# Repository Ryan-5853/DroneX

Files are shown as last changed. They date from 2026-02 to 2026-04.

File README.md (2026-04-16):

# DroneX(推进中)

推力矢量可回收火箭式无人机 —— 重心高于推力点，通过共轴反桨与二轴云台实现姿态控制，动力学特性类似 SpaceX Falcon 9 垂直着陆。

## 项目概述

DroneX 采用**单一推力源 + 推力矢量偏转**的设计：

| 特性 | 描述 |
| --- | --- |
| 推进方式 | 共轴反桨，向下产生推力，自然抵消反扭矩 |
| 重心位置 | 高于推力作用点（倒立摆模型） |
| 控制机构 | 二轴云台（俯仰+滚转），高端无刷舵机驱动 |
| 飞行模式 | 悬停、平移、垂直降落（含自由落体段） |

与常规多旋翼不同，本机重心在推力之上，固有不稳定，需闭环控制保持姿态。

## 目录结构

```
DroneX/
├── docs/              # 项目文档
│   ├── PLAN.md        # 总体规划（动力学、架构、开发阶段）
│   ├── REFERENCES.md  # 参考文献索引
│   └── literature/    # 文献摘编
├── sim/               # 仿真（MATLAB/Simulink）
│   ├── matlab/        # 动力学模型、控制器、脚本、工具函数
│   ├── simulink/      # Simulink 模型
│   ├── data/          # 仿真输出
│   └── docs/          # 仿真计划、动力学模型、验证标准
├── mechanical/        # 机械设计
│   ├── docs/          # 设计计划、机架/推进/云台说明
│   ├── cad/           # CAD 源文件
│   ├── models/        # STL/STEP 导出
│   ├── drawings/      # 工程图
│   └── bom/           # 物料清单
└── firmware/          # 飞控固件（STM32H743 + HAL）
    ├── DroneX_STM32H743_Firmware/   # CubeMX + Keil 工程（主工程）
    ├── docs/          # 飞控设计文档
    └── hal_project/   # 空白 HAL 工程导入位置
```

## 快速入门

### 仿真

1. 安装 MATLAB R2021b+ 与 Simulink
2. 进入仿真目录并运行：
   ```matlab
   cd sim/matlab
   init_path
   run_basic_sim
   ```
   或直接运行：`cd sim/matlab/scripts; run_basic_sim`
3. 悬停验证：`run_verify_hover`（定点悬停 / 水平平移）
4. 详见 [sim/README.md](sim/README.md)

### 文档入口

- [总体规划](docs/PLAN.md) — 动力学模型、系统架构、子系统规划、开发阶段
- [参考文献](docs/REFERENCES.md) — TVC、倒立摆、共轴旋翼、飞行控制等文献
- [仿真计划](sim/docs/SIMULATION_PLAN.md) — 仿真目标、模块、验证标准
- [动力学模型](sim/docs/dynamics_model.md) — 坐标系、方程、参数（与 params.m 对齐）
- [机械设计计划](mechanical/docs/DESIGN_PLAN.md) — 管架、共轴产品、高端无刷舵机、材料与尺寸
- [飞控设计](firmware/docs/FLIGHT_CONTROL_DESIGN.md) — 软件架构、控制流程、驱动规划

## 技术栈

| 模块 | 工具 / 平台 |
| --- | --- |
| 仿真 | MATLAB、Simulink |
| 飞控 | STM32H743、CubeMX/HAL、Keil MDK-ARM |
| 机械 | 管架为主、3D 打印、现成共轴产品、高端无刷舵机 |
| 文档 | Markdown |

## 开发阶段

| 阶段 | 内容 |
| ---- | --- |
| P0 | 建模与仿真 |
| P1 | 机械初版 |
| P2 | 下位机基础 |
| P3 | 控制闭环、悬停 |
| P4 | 降落逻辑、鲁棒性优化 |

详见 [docs/PLAN.md](docs/PLAN.md)。

## 许可证

（待定）

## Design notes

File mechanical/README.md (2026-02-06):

# DroneX 机械设计子系统

## 概述

本目录包含 DroneX 可回收火箭式无人机的机械设计内容，包括机架、共轴推进单元、二轴云台等结构与装配设计。加工方式以 **3D 打印** 为主，必要时采用 CNC 加工。

## 设计目标

- **机架**：管架为主，火箭式细长外形，底部起落架，兼顾重心/推力点位置
- **共轴反桨单元**：现成共轴产品，到货后补充规格与安装接口
- **二轴云台**：俯仰轴 + 滚转轴，高端无刷舵机驱动
- **电池/载荷布局**：保证重心在推力点之上，满足倒立摆动力学要求（整机 ≤ 1 kg）

## 目录结构

```
mechanical/
├── docs/              # 机械设计文档
│   ├── DESIGN_PLAN.md # 设计计划与关键参数
│   ├── frame/         # 机架相关文档
│   ├── coax_unit/     # 共轴推进单元文档
│   └── gimbal/        # 二轴云台文档
├── cad/               # CAD 源文件（Fusion 360 / FreeCAD / STEP）
├── models/            # 导出模型（STL、STEP，用于 3D 打印与仿真）
├── drawings/          # 工程图（装配图、零件图）
└── bom/               # 物料清单（BOM）
```

## 输出物

| 类型 | 说明 |
| --- | --- |
| CAD 模型 | 零件与装配体源文件 |
| 工程图 | 装配说明、零件标注、加工图 |
| BOM | 物料清单，含规格与数量 |
| STL/STEP | 3D 打印用模型、仿真/外协用 |

## 相关文档

- [项目总览](../../docs/PLAN.md) - DroneX 项目总体规划
- [机械设计计划](./docs/DESIGN_PLAN.md) - 材料选型、关键尺寸约束、设计流程

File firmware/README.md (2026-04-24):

# DroneX 飞控固件子系统

基于 HAL 库的飞控固件与外围驱动，面向 DroneX 推力矢量可回收火箭式无人机。

## 简介

本子系统基于 **STM32H743** 与 **STM32CubeMX/HAL**，从零编写飞控固件，实现：

- 实时控制循环（200–500 Hz）
- IMU 姿态估计（互补滤波或 EKF）
- 电调与云台电机驱动
- 遥控接收与串口遥测
- 安全逻辑（低电压、失控、急停）

## 目录结构

```
firmware/
├── docs/                              # 飞控设计文档
│   └── FLIGHT_CONTROL_DESIGN.md       # 飞控设计主文档
├── DroneX_STM32H743_Firmware/         # CubeMX + Keil 工程（主工程）
│   ├── Core/                          # 主控逻辑、HAL 配置
│   ├── Drivers/                       # HAL、CMSIS
│   ├── MDK-ARM/                       # Keil 工程文件
│   └── *.ioc                           # CubeMX 配置
├── hal_project/                       # 空白 HAL 工程导入位置（可选）
└── README.md                          # 本文件
```

- **DroneX_STM32H743_Firmware/**：STM32CubeMX 生成的 HAL 工程，含 Keil MDK-ARM 项目文件
- **docs/**：飞控设计、驱动规划、控制流程等文档

## 硬件平台

| 组件 | 选型 |
| --- | --- |
| 主控 | STM32H743 |
| IMU | MPU6050 或 BMI088 |
| 电调 | BLHeli 或 ESC32 |
| 云台舵机 | 高端无刷舵机，PWM / SBUS 等舵机协议 |

## 参考系与物理量单位规定

    世界参考系：在初始化时与机体参考系对齐，随后保持与地面相对位姿不变
    机体参考系：俯视飞控板正面，向上为y轴正方向，向右为x轴正方向，垂直飞控板正面向上为z轴正方向，原点在机体质心
    传感器参考系：近似认为与飞控板姿态相同，但是原点在飞控板中心
    矢量单元参考系：俯视矢量舵盘，使两突出舵臂分别指向平面直角坐标系的x、y正方向，称为x臂和y臂，垂直矢量舵盘朝上为z正方向
                    两舵机分别称为x舵机、y舵机，当舵机臂水平于地面时，认为舵机打角为0，向上为正，向下为负，按照对称限幅归一化到-1~1
                    矢量单元朝向以roll/pitch表示，其中roll为绕y轴的转角，pitch为绕x轴的转角，遵循右手螺旋定则。即x舵机正向打角时，x臂上抬，矢量单元绕y轴逆向旋转；y舵机正向打角时，y臂上抬，矢量单元绕x轴正向旋转；

    长度、位移均以m为单位；质量以kg为单位；力以N为单位；角度以360分度为单位；时间以s为单位

## 开发阶段

对应项目主计划 [PLAN.md](../docs/PLAN.md) 中：

- **P2：下位机基础** — 飞控框架、IMU、电调、云台驱动，可手动操控的固件
- **P3：控制闭环** — 姿态闭环、悬停、简单轨迹

## 相关文档

- [飞控设计文档](docs/FLIGHT_CONTROL_DESIGN.md) — 软件架构、控制流程、驱动规划、安全逻辑
- [项目主计划](../docs/PLAN.md) — DroneX 总体规划、系统架构
- [动力学模型](../sim/docs/dynamics_model.md) — 坐标系、运动方程
- [飞行控制文献](../docs/literature/04-flight-control-and-estimation.md) — 姿态控制、状态估计
- [机械设计计划](../mechanical/docs/DESIGN_PLAN.md) — 云台舵机选型、限位

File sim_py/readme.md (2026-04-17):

# DroneX控制器仿真工程

## 仿真系统结构

### 接口数据结构定义
    按照信号类型分为位姿信号、控制信号、执行信号、力矩信号
    按照逻辑类型分为真值(物理世界理想信号)、采样值(考虑传感器噪声)、估计值(考虑建模误差与随机行为)

    一共有以下几种数据结构：
    POS_truth{//位姿真实值
        disp_xyz:三轴质心位移(世界参考系)
        att_quat:姿态四元数(世界参考系->机体参考系)
        vel_xyz:三轴质心线速度(世界参考系)
        acc_xyz:三轴质心加速度(世界参考系)
        angv_xyz:三轴角速度(机体参考系)
        anga_xyz:三轴角加速度(机体参考系)
    }

    Sensor_truth{//传感器系位姿真实值
        angv_xyz:三轴角速度(传感器参考系)
        acc_xyz:三轴加速度(传感器参考系)
    }
    //以上是Dynamics模块

    Sensor_obs{//传感器观测到的值，Sensor_truth带噪声
        angv_xyz:三轴角速度(传感器参考系)
        acc_xyz:三轴加速度(传感器参考系)
    }

    //以上是Sensor模块

    POS_est{//预测的机体位姿
        disp_xyz:三轴质心位移(世界参考系)
        att_quat:姿态四元数(世界参考系->机体参考系)
        vel_xyz:三轴质心线速度(世界参考系)
        acc_xyz:三轴质心加速度(世界参考系)
        angv_xyz:三轴角速度(机体参考系)
        anga_xyz:三轴角加速度(机体参考系)
    }

    //待定：预测算法的建模误差

    //以上是Estimator模块

    Ctrl_output{//控制器的输出
        thrust_xyz:目标推力矢量(机体系)
        torque_xyz:目标旋转扭矩(机体系)
    }

    //以上是Controller模块

    Ctrl_cmd{直接输出给执行器的控制信号
        Servo_x:使矢量单元沿x轴旋转的舵机占空比(在限幅内归一化)
        Servo_y:使矢量单元沿y轴旋转的舵机占空比(在限幅内归一化)
        Motor_P:正桨电机占空比
        Motor_N:反桨电机占空比
    }

    //以上是Allocator模块

    Actor_output{执行器输出的真实力矩
        Force_xyz:执行器作用在机体质心上的三轴力
        Torque_xyz:执行器作用在机体上、绕机体系三轴旋转的力矩
    }

    //以上是Actuator模块

    送入Dynamics积分

### Sensor(传感器模块)

模拟实机传感器模块的工作

读入真实位姿数据POS_truth,
    Sensor_err{//传感器安装误差
        disp_xyz:传感器参考系原点与机体参考系原点(质心)的位移误差
        disp_err:建模误差比例
        att_quat:机体参考系到传感器参考系的旋转姿态差
        att_err:建模误差比例
    }
以此为依据计算传感器系的真实位姿
为以上位姿添加噪声，模拟传感器噪声，传出Sensor_obs

### Estimator(位姿估计模块)

从传感器数据估计机体位姿

读入传感器系带噪声读数Sensor_obs
矫正、逆变换得到机体系位姿
位姿估计算法得到POS_est,传出

### Controller(控制器)

将位姿与目标位姿比较，输出控制矢量

读入估计位姿POS_est,更新控制器,输出Ctrl_output

### Allocator(执行器映射层)

根据目标控制矢量调整各执行器控制信号

读入Ctrl_output，通过执行器建模，计算执行器控制信号Ctrl_cmd

### Actuator(执行器模块)

根据控制信号，模拟执行器行为

读入Ctrl_cmd，根据执行器建模，加入噪声、随机行为、滞后、限幅等，输出模拟的实际输出物理量Actor_output

### Dynamics(物理仿真模块)

根据真实位姿和执行器实际输出更新真实位姿

读入Actor_output，按照运动学模型更新真实位姿，输出POS_truth

## 参考系与物理量单位规定

    世界参考系：在初始化时与机体参考系对齐，随后保持与地面相对位姿不变
    机体参考系：俯视飞控板正面，向上为y轴正方向，向右为x轴正方向，垂直飞控板正面向上为z轴正方向，原点在机体质心
    传感器参考系：近似认为与飞控板姿态相同，但是原点在飞控板中心
    矢量单元参考系：俯视矢量舵盘，使两突出舵臂分别指向平面直角坐标系的x、y正方向，称为x臂和y臂，垂直矢量舵盘朝上为z正方向
                    两舵机分别称为x舵机、y舵机，当舵机臂水平于地面时，认为舵机打角为0，向上为正，向下为负，按照对称限幅归一化到-1~1
                    矢量单元朝向以roll/pitch表示，其中roll为绕y轴的转角，pitch为绕x轴的转角，遵循右手螺旋定则。即x舵机正向打角时，x臂上抬，矢量单元绕y轴逆向旋转；y舵机正向打角时，y臂上抬，矢量单元绕x轴正向旋转；

    长度、位移均以m为单位；质量以kg为单位；力以N为单位；角度以360分度为单位；时间以s为单位

## 交互式可视化模块

可以使用交互式可视化模块实时观察仿真状态，支持输入期望姿态、期望速度、风力风向和扰动力，并以动画形式显示：

- 三维飞行器几何体（筒状机体 + 下方矢量单元）
- 飞行轨迹、推力方向
- 传感器读数、控制器输出、执行器输出

运行方式：

```bash
python -m sim_py.visualization
```

默认是紧凑UI（更流畅，组件更少）。如果需要完整调参滑块，可使用：

```bash
python -m sim_py.visualization --full-ui
```

可视化模块默认会加载一组首轮标定参数（见 sim_py/calibration.py），用于快速进入闭环调参状态。

界面右侧提供在线调参滑块，可实时修改：

- 控制器位置/速度环增益（Kp/Kd/Ki）
- 控制器姿态/角速度环增益（Kp/Kd/Ki）
- 推力与扭矩限幅
- 分配器推力映射增益、执行器电机推力增益

如果只做快速自检（不弹出GUI）：

```bash
python -m sim_py.visualization --headless-steps 200
```

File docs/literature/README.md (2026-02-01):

# 文献摘编目录

本目录按技术主题对 [REFERENCES.md](../REFERENCES.md) 中的文献做要点摘编，并与 [PLAN.md](../PLAN.md) 的工程描述对应，便于建模、控制与仿真时查阅。

| 文档 | 主题 | 与 DroneX 的关联 |
|---|---|---|
| [01-TVC-and-rocket-landing.md](01-TVC-and-rocket-landing.md) | 推力矢量控制与火箭垂直着陆 | 二轴云台 TVC、推力线不通过重心、力矩与力分配 |
| [02-inverted-pendulum-and-underactuated.md](02-inverted-pendulum-and-underactuated.md) | 倒立摆与欠驱动系统 | 重心高于推力点、开环不稳定、串级控制与 LQR |
| [03-coaxial-rotor-and-propulsion.md](03-coaxial-rotor-and-propulsion.md) | 共轴旋翼与推进器建模 | 共轴反桨、推力–转速关系、干扰系数 |
| [04-flight-control-and-estimation.md](04-flight-control-and-estimation.md) | 飞行控制与状态估计 | 姿态/位置 PID 或 LQR、控制分配、IMU 互补滤波或 EKF |
| [05-simulation-and-dynamics.md](05-simulation-and-dynamics.md) | 仿真与动力学建模 | 坐标系、平动/转动方程、Simulink/CIL、云台与推进器模型 |

**使用建议**：先阅 [REFERENCES.md](../REFERENCES.md) 获取完整书目与分类，再按需打开上表对应摘编文档查看公式与实现要点。

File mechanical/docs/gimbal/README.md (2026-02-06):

# 二轴云台

## 功能

俯仰轴 + 滚转轴，将推力矢量偏转，实现姿态控制与水平加速度。由两个**高端无刷舵机**驱动。

## 已确认

- **驱动方式**：高端无刷舵机（替代无刷直驱，降低驱动、通信、校准难度，性能相近）
- **选型**：待定

## 设计要点

- 轴系正交布置，俯仰 + 滚转
- 舵机协议：PWM / SBUS 等，便于飞控输出
- 机械限位与软件限位
- 线缆走线不干扰转动

## 选型后待补充

- 舵机型号、额定电压/电流
- 扭矩、角度范围、死区
- 安装孔位、尺寸、重量
- 通信协议与接线方式

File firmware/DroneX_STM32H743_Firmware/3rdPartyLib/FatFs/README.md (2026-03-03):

# FatFs - Generic FAT Filesystem Module

FatFs R0.15 (ChaN) - 嵌入式 FAT 文件系统库。

本目录包含 FatFs 核心源码，由 SD 卡驱动层引用。磁盘 I/O 接口（diskio）在 `User/Driver/SD/diskio_sd.c` 中实现。

## 文件说明

- `ff.c`, `ff.h` - FatFs 核心
- `ffconf.h` - 项目配置（无 RTOS、无 LFN、支持 f_printf）
- `diskio.h` - 磁盘 I/O 接口声明

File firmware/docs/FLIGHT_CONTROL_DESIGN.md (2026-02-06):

# DroneX 飞控设计文档

> 依据 [PLAN.md](../../docs/PLAN.md) 第 5.2 节及第 7 节「下位机计划」编写。

---

## 〇、已确认技术选型

| 项目 | 选择 |
| --- | --- |
| **主控** | STM32H743 |
| **HAL 库** | STM32CubeMX 生成 |
| **控制周期** | 200–500 Hz（内环 500 Hz，外环 100–200 Hz） |
| **IMU** | MPU6050 或 BMI088 |
| **电调** | BLHeli 或 ESC32 |
| **云台舵机** | 高端无刷舵机，PWM / SBUS 等舵机协议 |
| **姿态估计** | 互补滤波（首版）或 EKF（后续） |

---

## 一、目标与范围

### 1.1 目标

- 基于 HAL 库从零编写飞控固件与外围驱动
- 实现 P2 阶段「下位机基础」：飞控框架、IMU、电调、云台驱动
- 为 P3 控制闭环提供可烧录固件与驱动库

### 1.2 范围

- 飞控主控：STM32H743 + CubeMX/HAL，实时控制循环
- IMU：姿态估计（互补滤波或 EKF）
- 电调：主推进电机转速控制
- 云台舵机：高端无刷舵机（PWM/SBUS 等，驱动与校准简单）
- 通信：遥控接收、串口/无线遥测
- 安全逻辑：低电压保护、失控保护、急停

### 1.3 对应交付物（P2）

| 交付物 | 说明 |
| --- | --- |
| 可烧录固件 | 可手动操控的固件（油门、云台） |
| 驱动库 | IMU、ESC、云台舵机等驱动模块 |
| 参数配置工具 | 串口/地面站调参（可选） |

---

## 二、硬件平台

### 2.1 系统架构（引自 PLAN.md）

```mermaid
flowchart LR
    subgraph hw [硬件/下位机]
        FC[飞控主控]
        IMU[IMU]
        ESC[电调]
        GimbalMotor[云台舵机驱动]
    end
    
    subgraph sw [软件/控制]
        Est[状态估计]
        Ctrl[控制器]
        Alloc[控制分配]
    end
    
    FC --> IMU
    FC --> ESC
    FC --> GimbalMotor
    Est --> Ctrl
    Ctrl --> Alloc
    Alloc --> ESC
    Alloc --> GimbalMotor
```

### 2.2 主控

| 参数 | 规格 |
| --- | --- |
| 型号 | STM32H743 |
| 主频 | 480 MHz |
| 外设需求 | I2C（IMU）、PWM（电调、云台）、UART、ADC（电池电压） |

### 2.3 IMU

| 型号 | 接口 | 备注 |
| --- | --- | --- |
| MPU6050  | I2C | 六轴，成本低，易上手 |
| BMI088 | SPI/I2C| 精度更高，适合正式飞行 |

### 2.4 电调

| 类型 | 协议 | 备注 |
| --- | --- | --- |
| BLHeli | PWM / OneShot  | 通用，易采购 |
| ESC32 | UART/串口协议  | 闭环转速，可扩展 |

### 2.5 云台舵机

- 高端无刷舵机（参见 [mechanical/docs/DESIGN_PLAN.md](../../mechanical/docs/DESIGN_PLAN.md) 选型）
- 驱动方式：PWM / SBUS 等舵机协议，飞控输出脉宽或总线指令即可，无需 FOC、编码器、校准

### 2.6 通信接口

| 用途 | 接口 | 说明 |
| --- | --- | --- |
| 遥控接收 | SBUS/PPM | 油门、姿态指令、模式切换 |
| 遥测 | UART | 串口参数、状态上传 |
| 无线遥测 | 可选扩展 | WiFi/数传模块 |

---

## 三、软件架构

### 3.1 模块划分

| 层级 | 模块 | 职责 |
| --- | --- | --- |
| 应用层 | 状态估计 | IMU → 姿态、角速度 |
| 应用层 | 控制器 | 姿态/位置 PID 或 LQR |
| 应用层 | 控制分配 | 期望力/力矩 → T + (α, β) |
| 驱动层 | IMU 驱动 | I2C/SPI 读写、数据解析 |
| 驱动层 | ESC 驱动 | PWM/OneShot 输出 |
| 驱动层 | 云台驱动 | PWM/SBUS 舵机指令输出 |
| 驱动层 | 通信 | 遥控解析、串口遥测 |
| 系统层 | 任务调度 | 定时器、优先级、安全逻辑 |

### 3.2 任务调度

- **高优先级**：内环控制（角速度）500 Hz
- **中优先级**：外环控制（姿态、位置）100–200 Hz
- **低优先级**：遥测、参数更新、安全检测

实现方式：定时器中断 + 主循环，或 RTOS（FreeRTOS）按需引入。

---

## 四、控制流程

```mermaid
flowchart TB
    IMU[IMU 原始数据] --> Est[姿态估计]
    Est --> Att[姿态/角速度]
    RC[遥控指令] --> Pos[位置/姿态指令]
    Att --> Ctrl[姿态控制器]
    Pos --> Ctrl
    Ctrl --> Alloc[控制分配]
    Alloc --> ESC[ESC 推力 T]
    Alloc --> Gimbal[云台角 alpha beta]
    ESC --> Motor[主推进电机]
    Gimbal --> GimbalMotor[云台舵机]
```

数据流：IMU → 姿态估计 → 姿态/位置控制 → 控制分配 → ESC + 云台驱动。

坐标系与动力学约定参见 [sim/docs/dynamics_model.md](../../sim/docs/dynamics_model.md)。

---

## 五、驱动层规划

### 5.1 IMU 驱动

- 初始化：量程、采样率、滤波
- 数据读取：陀螺、加速度计原始值
- 单位转换：转为 rad/s、m/s²
- 对齐：机体系与 IMU 安装方向

### 5.2 电调协议

- PWM：1–2 ms 脉宽映射推力
- OneShot125/OneShot42：缩短最小脉宽，提高分辨率
- ESC32：若采用，需实现串口协议解析

### 5.3 云台舵机驱动

- **PWM 舵机**：脉宽映射期望角度（如 1–2 ms 对应角度范围）
- **SBUS 舵机**：若采用总线舵机，需解析 SBUS 协议或使用专用舵机库
- 限位：软件限位 + 机械限位（与 [mechanical/docs/gimbal/README.md](../../mechanical/docs/gimbal/README.md) 对齐）

### 5.4 遥控接收

- SBUS：串口协议，多通道
- PPM：单线多通道 PWM
- 解析：油门、俯仰/滚转/偏航指令、模式开关

### 5.5 串口遥测

- 输出：姿态、角速度、云台角、推力、电池电压
- 格式：自定义或 MAVLink 等标准协议（可选）

---

## 六、安全逻辑

| 项目 | 触发条件 | 动作 |
| --- | --- | --- |
| 低电压保护 | 电池电压 < 阈值 | 降推力、告警、逐步降落 |
| 失控保护 | 遥控信号丢失超时 | 悬停/降落/急停（可配置） |
| 急停 | 遥控急停开关 | 立即切断推力 |
| 上电自检 | 启动时 | IMU 校准、云台归中、电调初始化 |

---

## 七、与 HAL 工程的关系

### 7.1 hal_project 目录用途

- 本目录下 `hal_project/` 用于存放 STM32CubeMX 生成的 HAL 库空白工程
- 用户导入工程后，自研代码（状态估计、控制器、驱动）放在独立目录或 `hal_project/Core/` 下的自研模块中

### 7.2 CubeMX 配置建议

- 时钟：HSE + PLL，主频 480 MHz
- 定时器：用于控制周期（如 2 ms → 500 Hz）
- I2C：IMU（MPU6050/BMI088）
- PWM：电调通道、云台电机
- UART：遥控、遥测
- ADC：电池电压采样

### 7.3 自研代码与 HAL 的集成方式

- 在 `hal_project/Core/` 下创建 `dronex/` 或类似子目录，存放飞控应用与驱动
- 主循环或定时器中断中调用 `dronex_task_run()` 等入口
- 避免在 HAL 生成代码区域内手改，通过 `USER CODE` 块或外部调用集成

---

## 八、里程碑与依赖

| 子任务 | 依赖 | 产出 |
| --- | --- | --- |
| M0：框架搭建 | HAL 工程导入 | 空循环、定时器、串口打印 |
| M1：IMU 驱动 | 框架 | IMU 数据读取与单位转换 |
| M2：电调驱动 | 框架 | PWM 输出、推力可控 |
| M3：云台驱动 | 框架 | 云台角可控 |
| M4：姿态估计 | IMU 驱动 | 互补滤波姿态输出 |
| M5：开环操控 | M1–M4 | 可手动操控的固件 |
| M6：闭环控制 | M5 + sim 参数  | 姿态闭环、悬停（P3） |

与 [PLAN.md](../../docs/PLAN.md) P2/P3 阶段对应：M0–M5 对应 P2，M6 对应 P3。

---

## 九、参考与引用

- [PLAN.md](../../docs/PLAN.md) §5.2 下位机/驱动子系统
- [PLAN.md](../../docs/PLAN.md) §6 开发阶段 P2、P3
- [sim/docs/dynamics_model.md](../../sim/docs/dynamics_model.md) — 坐标系、运动方程
- [docs/literature/04-flight-control-and-estimation.md](../../docs/literature/04-flight-control-and-estimation.md) — 姿态控制、状态估计、控制分配
- [mechanical/docs/DESIGN_PLAN.md](../../mechanical/docs/DESIGN_PLAN.md) — 云台舵机选型、限位

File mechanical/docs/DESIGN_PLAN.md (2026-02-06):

# DroneX 机械设计计划

> 依据 [PLAN.md](../../../docs/PLAN.md) 第 5.3 节及第 7 节细化方向编写。

## 〇、已确认设计决策（2025-02 更新）

| 项目 | 决策 |
| --- | --- |
| **整机重量** | ≤ 1 kg |
| **飞行时间** | 调试阶段不限，可有线供电 |
| **机架形式** | **管架为主**，火箭外形、细长、底部起落架 |
| **推进单元** | 现成共轴产品 [淘宝 871597014800](https://item.taobao.com/item.htm?id=871597014800) |
| **云台驱动** | **高端无刷舵机**（驱动、通信、校准简单，性能接近无刷直驱） |
| **桨罩** | 暂不定，后续补充 |

---

## 一、设计约束与目标

### 1.1 力学约束

| 约束项 | 要求 |
| --- | --- |
| **重心位置** | 重心必须高于推力作用点（倒立摆稳定所需）  |
| **推力点** | 与共轴推进器中心、云台旋转中心一致 |
| **对称性** | 质量分布尽量对称，减小惯性积 |

### 1.2 加工约束

| 项目 | 选择 |
| --- | --- |
| **主加工方式** | 3D 打印（FDM / 光固化）  |
| **补充加工** | CNC（金属件、高精度件）  |
| **材料** | 待定，见 §2 材料选型 |

---

## 二、材料选型

### 2.1 3D 打印材料（初版建议）

| 用途 | 推荐材料 | 特性 |
| --- | --- | --- |
| 机架主体 | PLA / PETG | 易打印、成本低、强度够 |
| 云台结构件 | PETG / ABS | 韧性好、耐冲击 |
| 桨罩 / 护壳  | PLA / TPU | 轻量、可柔性（TPU） |
| 高负荷关节 | 尼龙 / 碳纤增强 | 强度高、耐磨（可选） |

### 2.2 金属件（如采用 CNC）

| 用途 | 推荐材料 |
| --- | --- |
| 云台转轴 | 铝合金 6061 |
| 电机安装板 | 铝合金 2mm+ |
| 关键紧固件 | 不锈钢 M2/M3 |

---

## 三、关键尺寸约束

### 3.1 重心与推力点

```
        ↑ Z (竖直向上)
        │
        │    ● 重心 (CG)
        │    │
        │    │  h_cg   （重心到推力点垂直距离，需 > 0）
        │    │
        │    ▼ 推力作用点 (CP) ← 云台旋转中心
        │
        └──────────────────→
```

- **h_cg**：重心到推力点垂直距离，建议初版 50–150 mm
- **横向偏心**：尽量控制在 5 mm 以内

### 3.2 共轴反桨单元

| 参数 | 初版建议 | 说明 |
| --- | --- | --- |
| 桨直径 | 5–7 inch | 视推力与效率需求 |
| 上下桨间距 | 待仿真/试验  | 过小易干扰，过大增高度 |
| 桨罩直径 | 略大于桨径 | 兼顾保护与气流 |

### 3.3 二轴云台

| 参数 | 初版建议 | 说明 |
| --- | --- | --- |
| 俯仰角范围 | ±15°–±25° | 满足姿态控制需求 |
| 滚转角范围 | ±15°–±25° | 同上 |
| 偏转速度 | 待电机选型 | 需满足控制带宽 |
| 减速比 | 待定 | 兼顾力矩与响应 |

---

## 四、子系统设计要点

### 4.1 机架

- **形式**：**管架为主**，火箭式细长外形，底部起落架支撑
- **安装点**：电池舱、飞控舱、云台基座、共轴单元
- **强度**：校核悬停 + 最大偏转力矩下的应力

### 4.2 共轴反桨单元

- **选型**：采用现成共轴产品（见上方链接），降低开发量
- **桨罩**：暂不定，待推进单元到货后视安装接口决定
- **散热**：按产品说明，必要时加通风开孔

### 4.3 二轴云台

- **轴系**：俯仰轴 + 滚转轴，正交布置
- **电机**：高端无刷舵机（PWM/SBUS 等舵机协议），待选型后补充规格表
- **限位**：机械限位 + 软件限位

### 4.4 电池与载荷布局

- **电池**：尽量上置，配合重心要求
- **飞控/IMU**：靠近重心，减少振动
- **线缆**：走线不干扰云台转动

---

## 五、设计流程与里程碑

| 阶段 | 工作内容 | 交付物 |
| --- | --- | --- |
| **M0：概念** | 草图、尺寸估算、材料初选 | 概念草图、参数表 |
| **M1：详细设计** | 机架、共轴单元、云台 CAD 建模 | 零件与装配模型 |
| **M2：工程图** | 出图、BOM、加工说明 | 图纸、BOM |
| **M3：样机** | 打印/加工、装配、重心测量 | 可装配样机 |

---

## 六、待定事项

1. **推进单元规格**：到货后补充桨径、推力、安装尺寸、重量
2. **云台舵机规格**：选型后补充扭矩、角度范围、安装尺寸、重量、协议
3. **管架尺寸**：直径、壁厚、接头形式（待推进单元/云台尺寸确定）
4. **起落架**：支腿形式、展开角度、触地面积
5. **标准件**：螺丝、轴承规格统一

---

## 七、参考与引用

- [PLAN.md](../../../docs/PLAN.md) §1.2 关键技术参数
- [PLAN.md](../../../docs/PLAN.md) §5.3 机械设计子系统
- [PLAN.md](../../../docs/PLAN.md) §6 开发阶段 P1：机械初版

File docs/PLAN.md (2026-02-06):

# DroneX 可回收火箭式无人机计划文档

## 一、项目概念概述

### 1.1 核心设计理念

本项目设计一款**重心高于推力作用点**的无人机，通过**推力矢量控制 (TVC)** 实现姿态稳定与运动控制，力学特性类似 SpaceX Falcon 9 垂直着陆阶段的倒立摆系统。

```mermaid
flowchart TB
    subgraph propulsion [推进系统]
        Coax[共轴反桨推进器]
        TVC[二轴云台推力矢量]
    end
    
    subgraph dynamics [动力学特性]
        CG[重心高于推力点]
        Unstable[固有不稳定]
        Pendulum[倒立摆模型]
    end
    
    subgraph control [控制方式]
        Gimbal[云台偏转]
        ThrustDir[推力方向控制]
    end
    
    Coax --> TVC
    TVC --> ThrustDir
    CG --> Unstable
    Unstable --> Pendulum
    ThrustDir --> Pendulum
```

### 1.2 关键技术参数

| 特性 | 描述 |
| --- | --- |
| **推进方式** | 共轴反桨，向下产生推力，自然抵消反扭矩 |
| **重心位置** | 高于推力作用点（类似火箭着陆姿态） |
| **控制机构** | 二轴云台（俯仰+滚转），由两个高端无刷舵机驱动 |
| **飞行模式** | 悬停、平移、垂直降落（含自由落体段） |

**云台轴系选型**：采用俯仰+滚转，直接映射姿态控制需求，响应快、耦合小。偏航控制可通过共轴双桨轻微转速差或后续扩展方案实现。

### 1.3 与常规多旋翼的差异

- **常规多旋翼**：多个电机分散布局，通过各电机转速差实现姿态控制，重心通常低于或接近推力平面
- **本设计**：单一推力源 + 推力矢量偏转，重心在推力之上，控制难度更高但机械结构更紧凑

---

## 二、动力学模型

### 2.1 坐标系定义

- **惯性系**：地面固定，Z 轴向上
- **机体系**：原点在重心，随机体旋转
- **推力系**：随云台偏转，描述推力方向

### 2.2 主要方程

**平动**（牛顿第二定律）：

```
m·a = F_thrust + m·g + F_disturbance
```

其中 `F_thrust` 由云台偏转角 (θ_pitch, θ_roll) 和推力幅值 T 决定。

**转动**（欧拉方程）：

```
I·ω̇ + ω × (I·ω) = τ_thrust + τ_disturbance
```

`τ_thrust` 由推力作用点相对重心的力臂产生。

**倒立摆特性**：重心在推力之上时，推力偏转产生的力矩可稳定姿态，但开环系统不稳定，需闭环控制。

### 2.3 推力矢量与云台关系

云台偏转 (α, β) 将推力从机体 Z 轴偏转至空间方向，产生：

- 姿态控制力矩（推力线不通过重心）
- 水平加速度（推力有水平分量）

---

## 三、系统架构

```mermaid
flowchart LR
    subgraph mech [机械设计]
        Frame[机架]
        CoaxUnit[共轴推进单元]
        Gimbal[二轴云台]
    end
    
    subgraph hw [硬件/下位机]
        FC[飞控主控]
        IMU[IMU]
        ESC[电调]
        GimbalMotor[云台电机驱动]
    end
    
    subgraph sw [软件/控制]
        Est[状态估计]
        Ctrl[控制器]
        Alloc[控制分配]
    end
    
    subgraph sim [仿真]
        Phys[物理仿真]
        Env[环境模型]
    end
    
    Frame --> CoaxUnit
    Frame --> Gimbal
    CoaxUnit --> Gimbal
    FC --> IMU
    FC --> ESC
    FC --> GimbalMotor
    Est --> Ctrl
    Ctrl --> Alloc
    Alloc --> ESC
    Alloc --> GimbalMotor
    Phys --> sw
```

---

## 四、已确认的技术选型

| 项目 | 选择 |
| --- | --- |
| 仿真工具 | MATLAB（含 Simulink） |
| 飞控平台 | STM32H743，从 HAL 库自研飞控 |
| 机械加工 | 3D 打印为主，必要时 CNC |
| 文档格式 | Markdown |
| 云台轴系 | 俯仰 + 滚转 |

---

## 五、子系统规划

### 5.1 仿真子系统 (`/sim`)

**目标**：在实机开发前验证动力学模型和控制算法。

**工具链**：MATLAB（含 Simulink）

**已实现**（MATLAB 脚本）：

- 刚体动力学（rigid_body_ode）、推力模型（thrust_model）
- 姿态控制器、位置控制器（attitude_controller、position_controller）
- 工具函数：四元数/欧拉角、thrust_dir_to_att、animate_drone
- 运行脚本：run_basic_sim、run_verify_hover（定点悬停、水平平移验证）
- 参数配置：params.m

**内容**：

- 刚体动力学仿真（MATLAB/Simulink）
- 推进器模型：推力-转速关系、共轴干扰系数
- 云台动力学：俯仰+滚转二轴、电机响应、机械限位
- 控制器在环仿真 (CIL)
- 可选：Simscape Multibody 用于机械/接触仿真

**输出**：验证过的控制参数、轨迹规划结果。

### 5.2 下位机/驱动子系统 (`/firmware`)

**目标**：基于 HAL 库从零编写飞控固件与外围驱动。

**硬件平台**：STM32H743，工程位于 `firmware/DroneX_STM32H743_Firmware/`（CubeMX + Keil MDK-ARM）

**内容**：

- **飞控主控**：STM32H743 + CubeMX/HAL，实时控制循环 (200–500 Hz)
- **IMU**：MPU6050 / BMI088，姿态估计（互补滤波或 EKF）
- **电调**：BLHeli/ESC32，主推进电机转速控制
- **云台电机**：高端无刷舵机（PWM/SBUS 等舵机协议，驱动与校准简单）
- **通信**：遥控接收、串口/无线遥测
- **安全逻辑**：低电压保护、失控保护、急停

**输出**：可烧录固件、驱动库、参数配置工具。

### 5.3 机械设计子系统 (`/mechanical`)

**目标**：机架、云台、推进单元的结构与装配设计。

**加工方式**：以 3D 打印为主，需要时采用 CNC 加工。

**已确认设计决策**（详见 mechanical/docs/DESIGN_PLAN.md）：

- **整机重量**：≤ 1 kg
- **机架**：管架为主，火箭外形、细长、底部起落架
- **推进单元**：现成共轴产品
- **云台驱动**：高端无刷舵机
- **桨罩**：暂不定

**内容**：

- 机架：管架结构，兼顾强度与重心/推力点位置
- 共轴反桨单元：现成产品，到货后补充规格与安装接口
- 二轴云台：俯仰 + 滚转，高端无刷舵机，机械与软件限位
- 电池/载荷布局，保证重心在推力点之上
- 图纸、BOM、3D 打印 STL/STEP 文件，需 CNC 时的加工图

**输出**：CAD 模型、工程图、装配说明。

### 5.4 控制算法 (`/control` 或并入 `/sim`)

**目标**：姿态控制、位置/速度控制、控制分配。

**内容**：

- 姿态控制：串级 PID 或 LQR，内环角速度、外环姿态角
- 位置控制：外环位置/速度 PID
- 控制分配：期望力/力矩 → 推力幅值 T + 云台角 (α, β)
- 降落逻辑：悬停 → 减速下落 → 触地检测 / 缓冲

**输出**：算法文档、仿真验证结果、可移植到飞控的 C 代码。

---

## 六、开发阶段与里程碑

| 阶段 | 主要工作 | 交付物 |
| --- | --- | --- |
| **P0：建模与仿真** | 动力学推导、仿真环境搭建、控制器初步验证 | 仿真报告、控制参数初值 |
| **P1：机械初版**  | 机架、云台、推进单元 CAD 与样机 | 可装配样机 |
| **P2：下位机基础** | 飞控框架、IMU、电调、云台驱动 | 可手动操控的固件 |
| **P3：控制闭环**  | 姿态闭环、悬停、简单轨迹 | 悬停演示 |
| **P4：降落与优化** | 降落逻辑、参数优化、鲁棒性测试 | 完整飞行演示 |

---

## 七、后续细化方向

1. **动力学与建模**：坐标系约定见 sim/docs/dynamics_model.md，参数表已与 params.m 对齐
2. **仿真计划**：详见 sim/docs/SIMULATION_PLAN.md，MATLAB 脚本已实现基础闭环
3. **下位机计划**：详见 firmware/docs/FLIGHT_CONTROL_DESIGN.md
4. **机械设计计划**：详见 mechanical/docs/DESIGN_PLAN.md，已确认管架、共轴产品、高端无刷舵机
5. **控制算法计划**：控制结构已实现于 sim/matlab/controllers/，调参流程与鲁棒性待细化
6. **风险与应对**：技术风险清单待补充

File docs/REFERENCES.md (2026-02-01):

# DroneX 项目参考文献与文献索引

本文档按技术主题整理与 DroneX（推力矢量可回收无人机）相关的学术论文、书籍、标准与在线资源，便于建模、控制、仿真与实现时查阅。

---

## 一、推力矢量控制与火箭垂直着陆

| 类型 | 文献 | 说明 |
|---|---|---|
| 论文 | Blackmore, L., *et al.*, "Guidance and Control for Lunar Descent and Landing," *AIAA Guidance, Navigation and Control Conference*, 2008 | 月球着陆段制导与控制，与 TVC 着陆段问题相近 |
| 论文 | Ebrahimi, B., *et al.*, "Modeling and Control of a Single-Axis Thrust-Vectoring UAV," *Journal of Guidance, Control, and Dynamics*, 2018 | 单轴推力矢量 UAV 建模与控制，可直接类比本项目的俯仰/滚转 TVC |
| 论文 | Slegers, N., Kyle, J., "Nonlinear Model Predictive Control for a Thrust-Vectored Flying Wing," *AIAA Guidance, Navigation and Control Conference*, 2009 | 推力矢量飞行器非线性模型预测控制 |
| 技术报告 | SpaceX, Falcon 9 Landing Technology (公开资料与发布会) | 垂直着陆姿态与 TVC 工程实现参考 |
| 书籍 | Tewari, A., *Atmospheric and Space Flight Dynamics*, Birkhäuser, 2007 | 大气/空间飞行动力学，含推力矢量与姿态动力学 |

---

## 二、倒立摆与欠驱动系统控制

| 类型 | 文献 | 说明 |
|---|---|---|
| 书籍 | Åström, K.J., Murray, R.M., *Feedback Systems: An Introduction for Scientists and Engineers*, 2nd ed., Princeton, 2021 | 反馈系统与稳定性，倒立摆经典例题 |
| 论文 | Fantoni, I., Lozano, R., *Non-linear Control for Underactuated Mechanical Systems*, Springer, 2002 | 欠驱动机械系统非线性控制，含摆类系统 |
| 论文 | Spong, M.W., "The Swing Up Control Problem for the Acrobot," *IEEE Control Systems Magazine*, 1995 | 欠驱动摆的起摆与稳定，控制思路可借鉴 |
| 论文 | Bouabdallah, S., *et al.*, "Design and Control of an Indoor Micro Quadrotor," *ICRA*, 2004 | 微四旋翼姿态控制，与重心在推力之上的稳定性问题相关 |
| 标准/教程 | MathWorks, "Inverted Pendulum" (Control System Toolbox / Simulink 示例) | 倒立摆建模与 LQR/PID 仿真参考 |

---

## 三、共轴旋翼与推进器建模

| 类型 | 文献 | 说明 |
|---|---|---|
| 论文 | Leishman, J.G., "Principles of Helicopter Aerodynamics," 2nd ed., Cambridge, 2006 | 旋翼气动基础，共轴双桨干扰与拉力/扭矩 |
| 论文 | Coleman, C.P., "A Survey of Theoretical and Experimental Coaxial Rotor Aerodynamic Research," NASA TM 3675, 1997 | 共轴旋翼理论与实验综述 |
| 论文 | Kim, S.K., *et al.*, "Design and Implementation of a Coaxial Quadrotor with Tiltable Rotors," *ICUAS*, 2016 | 共轴 + 倾转机构，推力矢量与旋翼布局 |
| 论文 | Prouty, R.W., *Helicopter Performance, Stability, and Control*, Krieger, 1995 | 直升机性能与稳定性，旋翼推力/扭矩建模 |
| 在线 | UIUC Airfoil Data, NACA/APC 桨叶数据 | 螺旋桨升力/阻力系数与雷诺数修正 |

---

## 四、飞行控制与状态估计

| 类型 | 文献 | 说明 |
|---|---|---|
| 书籍 | Stevens, B.L., *et al.*, *Aircraft Control and Simulation*, 3rd ed., Wiley, 2016 | 飞行器控制与仿真，欧拉角/四元数、PID 与 LQR |
| 书籍 | Tewari, A., *Advanced Control of Aircraft, Spacecraft and Rockets*, Wiley, 2011 | 飞行器/航天器先进控制，含推力矢量与姿态回路 |
| 论文 | Mahony, R., *et al.*, "Nonlinear Complementary Filters on the Special Orthogonal Group," *IEEE TAC*, 2008 | 姿态互补滤波在 SO(3) 上的严格形式，适合 IMU 姿态估计 |
| 论文 | Simon, D., *Optimal State Estimation*, Wiley, 2006 | 最优状态估计，EKF 与姿态四元数 EKF |
| 论文 | Bresciani, T., "Modelling, Identification and Control of a Quadrotor Helicopter," *Lund University*, 2008 | 四旋翼建模、辨识与控制，流程可迁移到 TVC 无人机 |

---

## 五、仿真与动力学建模

| 类型 | 文献 | 说明 |
|---|---|---|
| 书籍 | Zipfel, P.H., *Modeling and Simulation of Aerospace Vehicle Dynamics*, 3rd ed., AIAA, 2007 | 飞行器动力学建模与仿真，坐标系与欧拉方程 |
| 书籍 | Jazar, R.N., *Advanced Dynamics*, Wiley, 2020 | 刚体动力学、多体系统与欧拉角奇异点 |
| 文档 | MathWorks, *Aerospace Blockset* / *Simscape Multibody* 用户手册 | 六自由度刚体、推进器与多体机械仿真 |
| 论文 | Luukkonen, T., "Modelling and Control of Quadcopter," *Aalto University*, 2011 | 四旋翼 Simulink 建模与控制器在环仿真 |
| 标准 | IEEE/ISO 坐标系与姿态表示 (例如 NED/ENU) | 惯性系与机体系定义，与 PLAN.md 中约定一致 |

---

## 六、嵌入式飞控与硬件实现

| 类型 | 文献 | 说明 |
|---|---|---|
| 手册 | STM32H743 Reference Manual & CubeMX/HAL 文档 | 主控、定时器、ADC、通信与实时循环 |
| 论文 | Premerlani, W., Bizard, P., "Direction Cosine Matrix IMU: Theory," 2009 (开源笔记) | DCM/互补滤波在嵌入式上的实现 |
| 文档 | Betaflight / PX4 架构与状态机说明 (GitHub/Wiki) | 飞控任务调度、安全逻辑与参数配置思路 |
| 手册 | BLHeli_S / ESC32 电调协议与 PWM/OneShot | 电机转速与推力指令接口 |
| 书籍 | Valvano, J.W., *Embedded Systems*, 4th ed., 2019 | 嵌入式实时系统与外设驱动 |

---

## 七、垂直起降与降落逻辑

| 类型 | 文献 | 说明 |
|---|---|---|
| 论文 | Polack, P., *et al.*, "The MIT Duckietown Autonomous Driving Project," (可类比地面触地与安全逻辑) | 自主系统的状态机与安全约束 |
| 论文 | 各类 VTOL 与 eVTOL 降落轨迹规划文献 | 减速段、接地检测与缓冲策略 |
| 标准 | DO-178C / DO-331 (机载软件) | 高可靠性飞控软件开发参考（若需合规） |

---

## 使用建议

- **建模与仿真**：优先参阅 *Zipfel*、*Stevens*、*Tewari (Atmospheric)* 与 MATLAB Aerospace/Simulink 文档。  
- **控制算法**：从 *Åström*、*Stevens*、*Tewari (Advanced)* 与 *Ebrahimi (TVC UAV)* 入手，再结合倒立摆与欠驱动文献。  
- **共轴推进**：*Leishman*、*Coleman* 与 *Prouty* 用于推力/扭矩与干扰系数建模。  
- **嵌入式实现**：STM32 HAL、Betaflight/PX4 架构与 *Premerlani* 的 DCM/互补滤波实现。  

如需某主题的详细摘编或公式推导，可参见 `docs/literature/` 下对应主题的文献摘编文档。

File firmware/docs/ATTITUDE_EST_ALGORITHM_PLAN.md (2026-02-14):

# 双正交 IMU 姿态估计算法设计计划

> 在 `Algorithm/Attitude_Est` 中实现融合两个正交 IMU 的姿态估计算法。

---

## 一、现状与目标

### 1.1 硬件现状

| 项目 | 规格 |
|---|---|
| IMU 型号 | ICM42688 × 2（六轴：陀螺 + 加速度计） |
| 安装方式 | **正交安装**（两个 IMU 敏感轴相互正交 90°） |
| 采样率 | 200 Hz（IMU 读取） |
| 解算率 | 100 Hz（姿态任务） |
| 数据单位 | gyro [rad/s]，accel [m/s²] |

### 1.2 正交双 IMU 的优势

- **冗余测量**：同一物理量（角速度、加速度）由两个正交轴系测量，可降低噪声、提高精度
- **故障检测**：两个独立 IMU 可做一致性检验，检测单 IMU 故障
- **偏置估计**：多传感器融合可更好估计陀螺/加速度计偏置

### 1.3 设计目标

1. 将两个正交 IMU 的测量统一到**机体系**（body frame）
2. 融合后输出：姿态（四元数/欧拉角）、角速度、加速度
3. 支持 IMU 校准（偏置估计）
4. 算法在 STM32H743 上实时运行（100 Hz）

---

## 二、算法选型

### 2.1 推荐方案：分阶段实现

| 阶段 | 算法 | 复杂度 | 适用场景 |
|---|---|---|---|
| **P1（首版）** | 互补滤波 + 正交融合 | 低 | 快速验证、资源受限 |
| **P2（进阶）** | 扩展卡尔曼滤波（EKF） | 中 | 精度提升、偏置在线估计 |
| **P3（可选）** | 考虑传感器位置的集中式 EKF | 高 | 两 IMU 距离较大时 |

### 2.2 算法详解

#### 方案 A：互补滤波 + 正交融合（推荐首版）

**原理**：
- 陀螺：低频漂移、高频响应好 → 用于姿态积分
- 加速度计：高频噪声大、低频可测重力方向 → 用于姿态修正
- 互补滤波：高通滤陀螺、低通滤加速度计，两者互补

**正交融合策略**：
1. **坐标系转换**：将 IMU2 的测量通过安装旋转矩阵 \( R_{2 \to 1} \) 转换到 IMU1（或机体系）
2. **数据融合**：对转换后的角速度、加速度做**加权平均**或**最优线性组合**
3. **姿态解算**：对融合后的角速度积分，用融合后的加速度做倾角修正

**优点**：实现简单、计算量小、易于调试  
**缺点**：偏置需离线校准，无在线估计

---

#### 方案 B：扩展卡尔曼滤波（EKF）

**原理**：
- 状态向量：\( x = [q, \omega, b_\omega, b_a]^T \)（四元数、角速度、陀螺偏置、加速度偏置）
- 预测：陀螺积分姿态，偏置建模为随机游走
- 更新：加速度计测量重力方向、两个 IMU 的冗余测量作为观测

**正交融合**：
- 将 IMU2 测量转换到机体系后，作为**额外观测**进入 EKF 测量方程
- 观测噪声协方差可根据传感器质量设置不同权重

**优点**：最优线性估计、可在线估计偏置、理论完备  
**缺点**：实现复杂、需调参（Q、R 矩阵）

---

#### 方案 C：集中式 Kalman 滤波（考虑传感器位置）

**适用**：两个 IMU **非共点安装**（存在位移）时。

**原理**（参考 MDPI Sensors 2018）：
- 加速度计受**离心加速度** \( \omega \times (\omega \times r) \) 和**切向加速度** \( \dot{\omega} \times r \) 影响
- 通过 Grubin 变换将各 IMU 测量统一到质心
- 状态包含各 IMU 偏置，集中式滤波同时估计

**适用条件**：两 IMU 间距 > 数毫米且角速度较大时才有显著影响。  
**本项目**：若两 IMU 紧贴或共点，可**不考虑**传感器位置，简化实现。

---

## 三、正交安装与坐标系

### 3.1 安装约定

设：
- **机体系** \( \mathcal{B} \)：以 IMU1 为参考，或取机体几何中心
- **IMU1 系**：与机体系对齐（或已知固定变换）
- **IMU2 系**：相对 IMU1 **正交安装**，即 \( R_{2 \to 1} \) 为 90° 旋转矩阵

**典型正交配置示例**（绕 Z 轴转 90°）：
```
IMU1: X→前, Y→右, Z→下
IMU2: X→右, Y→后, Z→下  （绕 Z 转 90°）
```
则 \( R_{2 \to 1} \) 将 IMU2 的 (x,y,z) 映射到机体系的 (y,-x,z)。

### 3.2 转换公式

设 IMU2 测量为 \( \omega_2, a_2 \)（其本体系），则机体系下：
```
ω_body = R_{2→1} · ω_2
a_body = R_{2→1} · a_2
```

**注意**：具体 \( R_{2 \to 1} \) 需根据**实际 PCB 布局与机械安装**确定，应在 `Attitude_Est` 中可配置。

---

## 四、模块与接口设计

### 4.1 目录结构

```
User/
├── Algorithm/
│   └── Attitude_Est/
│       ├── Attitude_Est.h      # 对外接口
│       ├── Attitude_Est.c      # 主逻辑：融合 + 姿态解算
│       ├── Attitude_Est_Fusion.c   # 正交融合（坐标变换 + 加权）
│       ├── Attitude_Est_Filter.c   # 互补滤波 / EKF
│       └── Attitude_Est_Config.h   # 安装矩阵、滤波参数
├── Application/
│   └── Attitude/               # 应用层：调用 Algorithm，处理校准请求
│       ├── Attitude.c
│       └── Attitude.h
└── ...
```

### 4.2 数据流

```
IMU1 原始数据 ──┐
                ├──→ 正交融合 ──→ 融合后 (ω, a) ──→ 姿态滤波 ──→ 姿态输出 (q, euler, ω)
IMU2 原始数据 ──┘
```

### 4.3 接口定义（草案）

```c
/* 输入：两个 IMU 的原始数据（机体系或需转换） */
void Attitude_Est_Update(const IMU_Data_t *imu1, const IMU_Data_t *imu2, float dt_s);

/* 输出：姿态、角速度 */
void Attitude_Est_GetQuat(float q[4]);
void Attitude_Est_GetEuler(float *roll_rad, float *pitch_rad, float *yaw_rad);
void Attitude_Est_GetAngularRate(float omega[3]);

/* 校准：设置偏置（由 Attitude 应用层调用） */
void Attitude_Est_SetBias(int imu_id, const IMU_Bias_t *bias);
```

---

## 五、实现步骤（P1 互补滤波 + 正交融合）

### Step 1：坐标系与融合

1. 定义 `R_imu2_to_body`（3×3 旋转矩阵），根据实际安装填写
2. 实现 `Attitude_Est_Fusion_Update(imu1, imu2, &omega_fused, &acc_fused)`
   - 将 IMU2 转换到机体系
   - 角速度：(ω1 + R·ω2) / 2 或按方差加权
   - 加速度：同理

### Step 2：互补滤波姿态解算

1. 姿态表示：四元数 q
2. 预测：\( q_{k+1} = q_k \otimes \exp(\omega \cdot dt) \)（或一阶欧拉积分）
3. 修正：用加速度计估计的倾角与当前姿态比较，生成修正角速度，注入互补滤波
4. 经典形式：`angle = α * (angle + ω*dt) + (1-α) * accel_angle`，α 为高通系数

### Step 3：与 Application 层对接

1. `Attitude_Task` 中获取 IMU1、IMU2 数据（需在 User_main 或数据总线中提供）
2. 调用 `Attitude_Est_Update(imu1, imu2, 0.01f)`
3. 将 `Attitude_Est_GetEuler` 等结果供控制或遥测使用

### Step 4：校准集成

1. `Attitude_RequestImuCali` 触发后，在静止期采集数据
2. 计算陀螺偏置（均值）、加速度计偏置（与重力对比）
3. 调用 `Attitude_Est_SetBias` 写入，后续测量中减去

---

## 六、参数与可调项

| 参数 | 含义 | 典型值 |
|---|---|---|
| 互补滤波系数 α | 陀螺权重（高通） | 0.96 ~ 0.98 |
| 融合权重 | IMU1 vs IMU2 | 0.5/0.5 或按噪声方差 |
| 解算周期 dt | 姿态更新周期 | 0.01 s（100 Hz） |
| 安装矩阵 | R_imu2_to_body | 由机械确定 |

---

## 七、参考文献

1. **Data Fusion Architectures for Orthogonal Redundant Inertial Measurement Units** (MDPI Sensors 2018) — 正交冗余 IMU 的集中式/分布式融合
2. **A new orthogonalization and sensor fusion algorithm for attitude estimation** (IEEE) — 正交化与传感器融合
3. **Madgwick AHRS** — 梯度下降姿态融合，可作互补滤波的替代
4. **PX4 / Betaflight** — 开源飞控姿态估计实现参考

---

## 八、总结

| 项目 | 建议 |
|---|---|
| **首版算法** | 互补滤波 + 正交融合（加权平均） |
| **姿态表示** | 四元数（避免万向锁） |
| **融合方式** | 坐标变换后等权平均，后续可按方差加权 |
| **进阶方向** | EKF 在线偏置估计、故障检测 |
| **安装矩阵** | 必须根据实际 PCB 与机械安装标定 |

建议先实现 **P1 互补滤波 + 正交融合**，验证双 IMU 数据流与姿态输出正确后，再考虑引入 EKF 或更复杂的融合架构。

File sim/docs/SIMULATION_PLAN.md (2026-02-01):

# DroneX 仿真计划

仿真子系统的目标、结构、流程与验证标准。对应项目主计划 [PLAN.md](../docs/PLAN.md) 中 P0 阶段与仿真子系统规划。

---

## 1. 目标与范围

### 1.1 目标

- 在实机开发前验证动力学模型与控制算法
- 提供可调参数初值，供 P2/P3 阶段飞控与闭环控制使用
- 支持轨迹规划与降落逻辑的离线验证

### 1.2 范围

- 刚体六自由度动力学
- 推进器与云台子模型
- 姿态与位置控制器
- 控制器在环仿真 (CIL)

### 1.3 对应交付物（P0）

| 交付物 | 说明 |
| --- | --- |
| 仿真报告 | 模型验证结果、典型场景仿真曲线、结论 |
| 控制参数初值 | PID/LQR 等参数，供飞控移植与调优 |

---

## 2. 工具链

| 组件 | 版本/要求 | 用途 |
| --- | --- | --- |
| MATLAB | R2021b 或更高 | 脚本、函数、数据处理 |
| Simulink | 随 MATLAB | 动力学与控制仿真 |
| Simscape Multibody | 可选 | 机械/接触仿真（后续扩展）|

---

## 3. 模块规划

```mermaid
flowchart TB
    subgraph plant [被控对象]
        RB[刚体动力学]
        Prop[推进器模型]
        Gimbal[云台动力学]
    end
    
    subgraph ctrl [控制]
        AttCtrl[姿态控制器]
        PosCtrl[位置控制器]
        Alloc[控制分配]
    end
    
    subgraph env [环境]
        Grav[重力]
        Dist[扰动模型]
    end
    
    AttCtrl --> Alloc
    PosCtrl --> AttCtrl
    Alloc --> Prop
    Alloc --> Gimbal
    Prop --> RB
    Gimbal --> RB
    Grav --> RB
    Dist --> RB
```

### 3.1 刚体动力学

- 平动：牛顿第二定律，机体系与惯性系转换
- 转动：欧拉方程，四元数/欧拉角姿态表示
- 参考：[dynamics_model.md](dynamics_model.md)

### 3.2 推进器模型

- 推力与转速关系（待测或基于经验公式）
- 共轴干扰系数（上/下桨效率差异）
- 建模位置：`matlab/models/`、`simulink/models/` 或 `simulink/lib/`

### 3.3 云台动力学

- 俯仰 + 滚转二轴
- 电机响应（一阶或二阶近似）、机械限位
- 输入：期望云台角 (α, β)；输出：实际云台角及角速度

### 3.4 控制器

- 姿态控制：内环角速度、外环姿态（串级 PID 或 LQR）
- 位置控制：外环位置/速度 PID
- 控制分配：期望力/力矩 → 推力幅值 T + 云台角 (α, β)
- 建模位置：`matlab/controllers/` 或 Simulink 子模块

### 3.5 环境扰动

- 重力（常值）
- 风/阵风（可选，用于鲁棒性测试）

---

## 4. 项目结构

| 路径 | 职责 |
| --- | --- |
| `sim/docs/` | 仿真文档（本计划、动力学、验证） |
| `sim/matlab/init_path.m` | 路径初始化（添加 models、controllers、utils、scripts） |
| `sim/matlab/models/` | 动力学、推进器、云台等 M 函数（rigid_body_ode、thrust_model） |
| `sim/matlab/controllers/`| 姿态控制器、位置控制器 |
| `sim/matlab/utils/` | 四元数/欧拉角、thrust_dir_to_att、animate_drone |
| `sim/matlab/scripts/` | params、run_basic_sim、run_verify_hover |
| `sim/simulink/models/` | 主仿真 .slx 模型 |
| `sim/simulink/lib/` | 可复用 Simulink 库块 |
| `sim/data/results/` | 仿真输出、日志、绘图 |

---

## 5. 仿真流程

```mermaid
flowchart LR
    A[参数配置] --> B[模型加载]
    B --> C[运行仿真]
    C --> D[结果分析]
    D --> E[报告导出]
```

### 5.1 参数配置

- 在 `matlab/scripts/` 中定义或加载 `params.m` 等
- 包含：质量、惯量、重心/推力点、推进器系数、云台限位、控制参数

### 5.2 模型加载

- 启动 MATLAB 后，将 `sim/matlab` 加入路径
- 打开 Simulink 主模型，自动加载 Base Workspace 参数

### 5.3 运行仿真

- 设置仿真时长、求解器（ode4 等固定步长推荐）
- 运行 Simulink 或调用 `sim()` 脚本

### 5.4 结果分析

- 姿态角、角速度、位置、速度曲线
- 云台角、推力、控制量
- 与 [verification.md](verification.md) 中指标对比

### 5.5 报告导出

- 将典型曲线保存至 `data/results/`
- 生成仿真报告（Markdown 或 PDF）

---

## 6. 验证标准

详见 [verification.md](verification.md)，概要如下：

- **姿态稳定**：阶跃响应上升时间、超调、稳态误差
- **悬停**：位置/速度误差、姿态偏差
- **抗扰**：施加扰动后的恢复时间与残余误差

---

## 7. 里程碑与依赖

| 子任务 | 依赖 | 产出 |
| --- | --- | --- |
| 动力学方程推导与参数表 | 无 | dynamics_model.md 定稿 |
| 刚体动力学 Simulink 实现 | 动力学方程 | 六自由度仿真块 |
| 推进器与云台模型 | 参数/实测数据 | 推力与云台子模块 |
| 控制器初步设计 | 控制算法方案 | 姿态/位置控制器模块 |
| 开环验证 | 刚体+推进器+云台 | 开环响应曲线 |
| 闭环验证 | 控制器+闭环结构 | 闭环响应、参数初值 |
| 仿真报告 | 闭环验证、验证标准 | 报告文档、控制参数初值 |

---

## 8. 与主文档的关联

- 总体规划：[docs/PLAN.md](../docs/PLAN.md)
- 动力学基础：PLAN.md 第二章；细化在 [dynamics_model.md](dynamics_model.md)
- 控制算法规划：PLAN.md 5.4；实现与验证在仿真子系统中完成

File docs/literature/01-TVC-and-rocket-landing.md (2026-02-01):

# 推力矢量控制与火箭垂直着陆 — 文献摘编

与 DroneX 的**二轴云台推力矢量**、**重心高于推力点**的力学特性直接相关。

---

## 1. 核心概念对应

| DroneX 设计 | 文献中的对应概念 |
|---|---|
| 云台偏转 (θ_pitch, θ_roll) | Thrust vectoring / gimbal deflection |
| 推力线不通过重心 → 姿态力矩 | Thrust vector moment / TVC authority |
| 垂直着陆段减速与姿态稳定 | Powered descent / terminal landing phase |

---

## 2. 推荐文献要点

### 2.1 单轴推力矢量 UAV（Ebrahimi 等）

- **题目**：Modeling and Control of a Single-Axis Thrust-Vectoring UAV  
- **与项目关系**：单轴 TVC 可视为本项目俯仰或滚转一维简化，建模思路（推力幅值 + 偏转角 → 力/力矩）可直接推广到二轴。
- **可借鉴**：  
  - 推力矢量产生的力矩表达式：τ = r × F_thrust，其中 r 为推力作用点到重心的矢量。  
  - 控制分配：期望力矩 → 推力大小 T 与云台角 α（或 β）。

### 2.2 火箭/着陆器制导与控制（Blackmore 等）

- **题目**：Guidance and Control for Lunar Descent and Landing  
- **与项目关系**：月球着陆的“动力下降段”同样面临：大推力、短时燃烧、姿态与轨迹耦合、终端约束（垂直速度、位置）。
- **可借鉴**：  
  - 制导律（如多项式轨迹、ZEM/ZEV）给出期望加速度/推力方向。  
  - 姿态控制器跟踪该推力方向，与 DroneX 中“位置环输出期望推力方向 + 姿态环跟踪”一致。

### 2.3 飞行动力学中的 TVC（Tewari, Atmospheric and Space Flight Dynamics）

- **与项目关系**：系统讲述推力矢量在体轴系下的分量、对转动方程的影响，以及欧拉角/四元数姿态方程。
- **常用公式**：  
  - 推力在机体系下：F_b = T · [sin(α)cos(β), sin(β), cos(α)cos(β)]^T（随云台角定义略作调整）。  
  - 力矩：τ = r_cp × F_b，r_cp 为推力作用点相对重心在体轴系下的坐标。

---

## 3. 与 PLAN.md 的衔接

- **平动**：`m·a = F_thrust + m·g + F_disturbance`，其中 `F_thrust` 由 T 与云台角 (θ_pitch, θ_roll) 确定，见上文 F_b。  
- **转动**：`I·ω̇ + ω×(I·ω) = τ_thrust + τ_disturbance`，τ_thrust 由 r_cp × F_thrust 得到。  
- **控制分配**：期望力 F_d、期望力矩 τ_d → 求解 (T, θ_pitch, θ_roll)，需考虑推力限幅与云台机械限位。

---

## 4. 延伸阅读

- Slegers, N., Kyle, J., "Nonlinear Model Predictive Control for a Thrust-Vectored Flying Wing" — 推力矢量 + NMPC，若后续做约束与最优轨迹可参考。  
- SpaceX 公开的 Falcon 9 着陆视频与解说：直观理解大推力、短时、高精度姿态与位置协同。

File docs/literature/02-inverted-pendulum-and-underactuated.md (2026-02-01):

# 倒立摆与欠驱动系统 — 文献摘编

DroneX 的**重心高于推力作用点**，开环为**固有不稳定**，力学上等价于倒立摆；控制思路可借鉴倒立摆与欠驱动机械系统文献。

---

## 1. 与 DroneX 的对应关系

| 倒立摆/欠驱动系统 | DroneX |
|---|---|
| 摆角 θ | 机体俯仰/滚转角 |
| 摆的支点加速度或力矩输入 | 云台偏转产生的力矩 + 推力水平分量产生的加速度 |
| 欠驱动（少于一维一电机） | 推力幅值 T + 二轴云台 (α, β) 同时决定平动与转动，存在耦合与分配 |

---

## 2. 推荐文献要点

### 2.1 反馈系统与稳定性（Åström, Murray）

- **书名**：*Feedback Systems: An Introduction for Scientists and Engineers*  
- **与项目关系**：倒立摆作为经典例题，说明线性化、极点配置、LQR 与稳定性判据。
- **可借鉴**：  
  - 在平衡点（竖直向上）附近线性化，得到 θ̈ = (g/ℓ)θ + (1/(mℓ²))τ 形式。  
  - DroneX 中转动方程在悬停姿态附近线性化后，同样可得类似“不稳定极点 + 控制输入”的形式，便于设计 PID/LQR。

### 2.2 欠驱动机械系统（Fantoni, Lozano）

- **书名**：*Non-linear Control for Underactuated Mechanical Systems*  
- **与项目关系**：推力矢量机同时要稳定姿态（转动）和位置（平动），属于欠驱动、耦合系统。
- **可借鉴**：  
  - 级联控制：内环快速稳定姿态（角速度/姿态角），外环位置/速度产生“期望姿态或期望推力方向”。  
  - 与 PLAN.md 中“串级 PID，内环角速度、外环姿态角”一致；外环再套位置/速度环。

### 2.3 Acrobot 起摆与稳定（Spong）

- **题目**：The Swing Up Control Problem for the Acrobot  
- **与项目关系**：从任意初始角“起摆”到倒立位置并稳定，类比 DroneX 从大倾角恢复或起飞瞬态。
- **可借鉴**：  
  - 能量/基于能量的起摆律；稳定阶段切换为 LQR 或 PID。  
  - 若 DroneX 需从较大初始倾角（如放置倾斜）自主扶正，可参考切换逻辑与安全边界。

### 2.4 微四旋翼（Bouabdallah 等）

- **题目**：Design and Control of an Indoor Micro Quadrotor  
- **与项目关系**：四旋翼也是欠驱动、强耦合；部分文献讨论重心与推力平面不重合时的稳定性。
- **可借鉴**：  
  - 角速度内环 + 姿态外环的 PID 结构及参数数量级。  
  - 若引入“重心偏离几何中心”的模型，与 DroneX 的“重心在推力之上”在数学上同属一类耦合。

---

## 3. 与 PLAN.md 的衔接

- **倒立摆特性**：文档已写明“重心在推力之上时，推力偏转产生的力矩可稳定姿态，但开环系统不稳定，需闭环控制”。  
- **控制结构**：姿态控制采用“串级 PID 或 LQR，内环角速度、外环姿态角”；位置控制为外环位置/速度 PID；控制分配将期望力/力矩映射到 T 与云台角 (α, β)。  
- **降落逻辑**：悬停 → 减速下落 → 触地检测/缓冲，可与“稳定平衡点”的保持与安全切换一起设计。

---

## 4. 仿真与调参

- MathWorks “Inverted Pendulum” 示例：线性化、LQR 设计、Simulink 实现，可直接对照 DroneX 在 Simulink 中的姿态环设计。  
- 调参顺序建议：先在仿真中稳定内环角速度，再外环姿态角，最后位置环；实机时同样由内而外、逐步放开激励。

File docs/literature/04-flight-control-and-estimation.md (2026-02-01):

# 飞行控制与状态估计 — 文献摘编

面向 DroneX 的**姿态控制**、**位置/速度控制**、**控制分配**以及**IMU 姿态估计**（互补滤波或 EKF），便于算法设计与 C 代码实现。

---

## 1. 与 DroneX 的对应关系

| 主题 | 在项目中的作用 |
|---|---|
| 姿态表示与欧拉方程 | 机体系、惯性系、角速度与姿态角微分方程，与 PLAN.md 坐标系一致 |
| 姿态控制 (PID/LQR) | 内环角速度、外环姿态角，输出期望力矩 → 控制分配 |
| 位置/速度控制 | 外环 PID，输出期望加速度或期望推力方向 |
| 控制分配 | 期望力 F_d、力矩 τ_d → 推力 T + 云台角 (α, β) |
| 状态估计 | IMU 陀螺+加速度计 → 姿态（互补滤波或 EKF），角速度可直接用陀螺 |

---

## 2. 推荐文献要点

### 2.1 飞行器控制与仿真（Stevens 等）

- **书名**：*Aircraft Control and Simulation*  
- **与项目关系**：欧拉角/四元数、刚体转动方程、PID 与 LQR 设计流程，以及仿真框图。
- **可借鉴**：  
  - 欧拉角微分与角速度关系：φ̇, θ̇, ψ̇ 与 p, q, r 的转换；奇异点（θ = ±90°）及四元数替代。  
  - 串级控制：内环角速度阻尼，外环姿态角跟踪；LQR 权重选取与仿真验证。

### 2.2 先进飞行器/航天器控制（Tewari）

- **书名**：*Advanced Control of Aircraft, Spacecraft and Rockets*  
- **与项目关系**：推力矢量飞行器的姿态回路、制导与控制的层级划分。
- **可借鉴**：  
  - 姿态误差（四元数或欧拉角）到角速度指令、再到力矩指令的映射。  
  - 与 PLAN.md 中“控制分配：期望力/力矩 → T + (α, β)”一致的整体结构。

### 2.3 互补滤波在 SO(3) 上的形式（Mahony 等）

- **题目**：Nonlinear Complementary Filters on the Special Orthogonal Group  
- **与项目关系**：仅用 IMU 时，陀螺积分易漂移，加速度计可提供重力方向约束；该文给出在 SO(3) 上严格、全局的互补滤波。
- **可借鉴**：  
  - 嵌入式上计算量适中，无需线性化；可得到一致、无奇异的姿态估计。  
  - 与 EKF 相比，实现简单，适合首版飞控；若需更高精度再考虑 EKF。

### 2.4 最优状态估计与 EKF（Simon）

- **书名**：*Optimal State Estimation*  
- **与项目关系**：若采用 EKF 做姿态估计，需处理四元数约束、观测模型（重力方向、磁强计等）。
- **可借鉴**：  
  - 四元数 EKF 的误差状态表示（避免四元数归一化与约束问题）。  
  - 观测方程：加速度计在静止/缓动时 ≈ 重力在机体系下的投影；磁强计可辅助偏航。

### 2.5 四旋翼建模与控制（Bresciani, Lund）

- **题目**：Modelling, Identification and Control of a Quadrotor Helicopter  
- **与项目关系**：从建模、参数辨识到控制器设计的完整流程，可迁移到 TVC 无人机。
- **可借鉴**：  
  - 系统辨识：阶跃/扫频激励、传递函数或状态空间辨识。  
  - 控制结构图、调参顺序（内环→外环）、鲁棒性考虑。

---

## 3. 与 PLAN.md 的衔接

- **姿态控制**：串级 PID 或 LQR，内环角速度、外环姿态角。  
- **位置控制**：外环位置/速度 PID。  
- **控制分配**：期望力/力矩 → T + (α, β)；需考虑 T 的范围与云台角限位，必要时加入伪逆或优化分配。  
- **下位机**：IMU（MPU6050/BMI088）、姿态估计（互补滤波或 EKF）、实时控制循环 200–500 Hz。

---

## 4. 实现建议

- **姿态表示**：推荐四元数存储，避免欧拉角奇异；显示或调试时可转换为欧拉角。  
- **控制周期**：内环（角速度）高于外环（姿态、位置）；与 PLAN.md 中 200–500 Hz 一致，内环可取 500 Hz，外环 100–200 Hz。  
- **控制分配**：二轴云台 + 单推力源时，(F_d, τ_d) 到 (T, α, β) 的映射有解析形式，注意 T > 0 与云台机械限位约束。

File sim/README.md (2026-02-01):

# DroneX 仿真子系统

在实机开发前验证动力学模型和控制算法的仿真环境。

## 简介

本子系统面向重心高于推力点的可回收火箭式无人机，通过 MATLAB/Simulink 实现：

- 刚体动力学仿真
- 推进器与云台模型
- 控制器在环仿真 (CIL)
- 控制参数与轨迹规划验证

## 目录结构

```
sim/
├── docs/                    # 仿真相关文档
│   ├── SIMULATION_PLAN.md   # 仿真计划（主文档）
│   ├── dynamics_model.md    # 动力学模型说明
│   └── verification.md      # 验证标准与用例
├── matlab/                  # MATLAB 脚本与函数
│   ├── init_path.m          # 路径初始化
│   ├── models/              # 动力学/推进器模型（rigid_body_ode、thrust_model）
│   ├── controllers/         # 姿态/位置控制器
│   ├── utils/               # 四元数、thrust_dir_to_att、animate_drone
│   └── scripts/             # params、run_basic_sim、run_verify_hover
├── simulink/                # Simulink 模型
│   ├── models/              # .slx 模型文件
│   └── lib/                 # 可复用库模块
├── data/                    # 仿真数据与结果
│   └── results/             # 运行输出、日志
└── README.md                # 本文件
```

## 环境要求

- **MATLAB**：R2021b 或更高版本
- **Simulink**：必选
- **Simscape Multibody**：可选，用于机械/接触仿真

## 快速入门

1. 打开 MATLAB，切换到项目目录
2. 运行基础仿真（自动添加路径）：
   ```matlab
   cd sim/matlab/scripts
   run_basic_sim
   ```
   或先初始化路径再运行：
   ```matlab
   cd sim/matlab
   init_path
   run_basic_sim
   ```
3. 将显示：时域曲线、3D 轨迹、姿态动画
4. 悬停验证：`run_verify_hover` 运行定点悬停 / 水平平移验证用例
5. 仿真结果可保存至 `data/results/`（在脚本中取消注释保存代码）

## 相关文档

- [仿真计划](docs/SIMULATION_PLAN.md) — 仿真目标、模块规划、流程与验证
- [动力学模型](docs/dynamics_model.md) — 坐标系、方程与参数
- [验证标准](docs/verification.md) — 验证指标与用例
- [项目主计划](../docs/PLAN.md) — DroneX 总体规划

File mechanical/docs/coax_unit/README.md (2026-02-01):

# 共轴反桨推进单元

## 功能

上下两层反向旋转的螺旋桨，向下产生推力，自然抵消反扭矩，作为整机唯一推力源。

## 已确认

- **选型**：现成共轴产品 [淘宝 871597014800](https://item.taobao.com/item.htm?id=871597014800)
- **桨罩**：暂不定

## 设计要点

- 到货后测量：桨径、上下桨间距、总高度、安装孔位、重量、标称推力
- 安装接口：与云台/机架的连接方式
- 散热：按产品说明，必要时增加通风

## 到货后待补充

- 桨直径、螺距、材质
- 电机型号、KV 值
- 总推力、推荐电调/电池规格
- 安装尺寸图（或实测尺寸表）

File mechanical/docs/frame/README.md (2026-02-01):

# 机架设计

## 功能

机架承载电池、飞控、载荷，并与共轴推进单元、二轴云台连接，是整机结构的骨架。外形类似**火箭**，细长，底部由起落架支撑。

## 已确认

- **形式**：管架为主
- **外形**：火箭式、细长
- **起落架**：底部支撑，具体形式待定

## 设计要点

- 管材：碳纤管 / 铝管 / 3D 打印分段管，便于加工与装配
- 保证重心在推力点之上（h_cg > 0）
- 电池舱、飞控舱沿轴向布置，配合细长外形
- 云台基座与共轴单元安装点刚性足够
- 起落架：着陆稳定性、触地面积、收纳/展开方式

## 待细化

- 管径、壁厚、接头形式（待推进单元/云台尺寸确定）
- 具体零件清单与装配顺序
- 强度校核
- 起落架支腿形式、展开角度

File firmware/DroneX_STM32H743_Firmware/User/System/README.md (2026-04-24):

# System 层状态机规范（草案）

本文档定义 `User/System` 的宏观状态机接口语义，当前阶段以“接口与注释先行”为目标，复杂保护逻辑保留 TODO。

## 1. 状态定义

- `STANDBY`（待命）  
  动力单元未激活，允许进行解锁条件检查。

- `READY`（就绪）  
  动力单元已激活，但不输出动力。

- `ERROR`（错误）  
  上电自检失败进入，禁止再次激活动力单元，需重启恢复。

- `RC`（遥控）  
  手动模式，遥控通道可直接映射油门/云台。

- `RUN`（运行）  
  自主决策模式（飞行策略待实现）。

- `PROTECT`（保护）  
  急停、遥测异常或硬件异常触发后锁定。只能通过 CLI 重启命令或断电重启恢复。

## 2. 关键迁移规则

### 上电

- 上电后执行自检：
  - 自检通过 -> `STANDBY`
  - 自检失败 -> `ERROR`（锁定）

### 待命到就绪

- `STANDBY -> READY` 当前解锁规则（先行实现版）：
  - 前四个通道 `CH1~CH4` 均在零位附近。
  - 左侧 `M/A` 开关（`CH5`）位于手动档（下位）。
  - 右侧 `SAFE` 开关（`CH8`）执行序列：
    - 初始位于中位。
    - 在 1 秒内先拨到下位，再拨到上位。
  - 上述条件满足后，`arm_condition_ok = true` 且 `cmd_to_ready = true`。
  - 不满足则保持 `STANDBY`，持续检测解锁条件。

### 激活态切换

- 当前通过左侧 `M/A`（`CH5`）决定激活态运行方式：
  - `CH5` 下位（手动） -> `RC`（遥控直通）
  - `CH5` 非下位（自动） -> `RUN`（当前输出占位为 0）
- `READY` 作为激活后中间态，随后按 `M/A` 进入 `RC` 或 `RUN`。

### 保护策略

- 任意状态收到以下事件之一，进入 `PROTECT`：
  - `estop`
  - `telemetry_abnormal`
  - `hardware_abnormal`
- `PROTECT` 为锁定态：不允许再次激活动力单元。

## 3. 恢复策略

- `ERROR`、`PROTECT` 均视为“需重启恢复”状态。
- 当前接口中通过 `cli_reboot_request` 触发状态机复位（等价于软件重启入口占位）。
- 实际产品建议最终走统一重启流程（命令行重启或硬件复位）。

## 4. 模块职责

- `System_StateMachine`  
  只负责状态迁移，不做硬件读写。

- `System_Safety`  
  汇总故障位图（当前已接 RC 丢失、ESC 更新异常，其他异常待实现）。

- `System_Telemetry`  
  打包系统状态快照，用于串口/地面站遥测。

- `System_Debug`  
  输出状态变化日志，便于联调。

- `System_Manager`  
  统一调度输入采样、安全判定、状态机更新和输出模块；并负责将动力指令按系统状态转发到驱动层。

## 5. 动力输出链路约束

- 未解锁（尤其 `STANDBY`）时，不允许发送 DShot 波形。
- 动力指令不得由业务层直接调用 ESC 驱动，必须经 `System_Manager_PowerControlTask` 转发。
- `RC` 模式：按遥控油门映射输出。
- `RUN` 模式：当前占位输出 `0`。

## 6. 当前占位与后续 TODO

- 自检输入当前由 `System_Manager` 占位为“通过”，需接入真实自检结果。
- 遥控器通道映射（解锁、模式切换）当前为占位逻辑，需按机型协议落地。
- `telemetry_abnormal`、`hardware_abnormal`、`estop` 仍需对接真实检测源。
- `RUN` 状态下自主飞行控制尚未实现。

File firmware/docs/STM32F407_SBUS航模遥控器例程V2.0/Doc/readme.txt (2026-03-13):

/**			                                                    
		   ____                    _____ _______ _____       XTARK@塔克创新
		  / __ \                  / ____|__   __|  __ \ 
		 | |  | |_ __   ___ _ __ | |       | |  | |__) |
		 | |  | | '_ \ / _ \ '_ \| |       | |  |  _  / 
		 | |__| | |_) |  __/ | | | |____   | |  | | \ \ 
		  \____/| .__/ \___|_| |_|\_____|  |_|  |_|  \_\
				| |                                     
				|_|                OpenCTR     机器人控制器                                 

【软件说明】
 * 软件名称：   SBUS航模遥控器数据解析例程 
 * 主要功能：   HOTRC航模遥控器SBUS数据解析，并通过串口输出
               支持所有型号，不同遥控器通道数不同，最多支持10个通道

【硬件说明】
 * 硬件平台：   OpenCTR H60 V3.2
 * 处理器：     STM32F407VET6
 * 高速晶振：   8MHz
 * 总线时钟：   系统时钟 = SYCCLK = AHB1 = 168MHz
 * 硬件接口：   参考开源硬件原理图
   
【其它说明】
 * 为了获取更好的阅读体验，建议将Tab size设置为4
 * 通过Edit菜单下，Configuration子菜单设置窗口的Editor标签页的“Tab size”选项设置

【硬件连接】
   
   SBUS信号经过转换后  ----  PD2（UART5 - RX）

【版本记录】
* V2.0 -2024年12月12日
  - 通道数改为10
  
* V1.0 -2024年8月24日
  - 版本初创

【版权信息】
  * 版权所有： XTARK@塔克创新  版权所有，盗版必究
  * 公司网站： www.xtark.cn   www.tarkbot.com
  * 淘宝店铺： https://xtark.taobao.com  
  * 塔克微信： 塔克创新（关注公众号，获取最新更新资讯）

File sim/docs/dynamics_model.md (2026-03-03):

# DroneX 动力学模型 — 定义性参考文档

本文档是仿真子系统的唯一数学标准。所有 MATLAB/Simulink 代码必须与本文档中的坐标系、符号、方程保持严格一致。

对应项目主计划 [PLAN.md](../../docs/PLAN.md) 第二章，以及仿真计划 [SIMULATION_PLAN.md](SIMULATION_PLAN.md)。

---

## 0. 约定总表（Quick Reference）

| 项目 | 约定 |
|---|---|
| 惯性系 {I} | 右手系，$Z_I$ 向上（ENU 类） |
| 机体系 {B} | 右手系，原点在 CG，$X_B$ 前，$Y_B$ 左，$Z_B$ 上 |
| 推力系 {T} | 云台坐标系，零偏转时与 {B} 对齐 |
| 重力 | $\mathbf{g}_I = [0;\ 0;\ -g]^T$，$g = 9.81\ \text{m/s}^2$ |
| 欧拉角序 | ZYX 内旋（yaw $\psi$ → pitch $\theta$ → roll $\varphi$） |
| 四元数 | Hamilton，标量在前 $q = [q_w;\ q_x;\ q_y;\ q_z]$ |
| 旋转矩阵 $R_{IB}$ | 机体系到惯性系：$\mathbf{v}_I = R_{IB}\,\mathbf{v}_B$ |
| 云台角 $\alpha$ | 俯仰，正值使推力偏向 $+X_B$ |
| 云台角 $\beta$ | 滚转，正值使推力偏向 $+Y_B$ |
| 推力点 | 在 CG 下方，$\mathbf{r}_T = [0;\ 0;\ {-l_T}]^T_B$ |
| 状态向量 | $\mathbf{x} = [\mathbf{p}_I;\ \mathbf{v}_I;\ \mathbf{q};\ \boldsymbol{\omega}_B]$，13 维 |
| 输入向量 | $\mathbf{u} = [T;\ \alpha;\ \beta]$，3 维 |

---

## 1. 坐标系定义

### 1.1 惯性系 {I}

| 属性 | 定义 |
|---|---|
| 原点 | 地面固定点 |
| $X_I$ | 水平，前方（任意参考方向） |
| $Y_I$ | 水平，指向左方（$Z_I \times X_I$ 的右手补集） |
| $Z_I$ | 向上 |
| 用途 | 描述位置、速度、重力方向 |

重力向量：

$$\mathbf{g}_I = \begin{bmatrix} 0 \\ 0 \\ -g \end{bmatrix},\quad g = 9.81\ \text{m/s}^2$$

### 1.2 机体系 {B}

| 属性 | 定义 |
|---|---|
| 原点 | 机体重心 (CG) |
| $X_B$ | 前方（机头方向） |
| $Y_B$ | 左方 |
| $Z_B$ | 上方（推力默认方向） |
| 用途 | 描述角速度、力矩、机载力 |

悬停时姿态为单位四元数 $q = [1;0;0;0]$，此时 {B} 与 {I} 重合。

### 1.3 推力/云台系 {T}

| 属性 | 定义 |
|---|---|
| 原点 | 推力作用点 |
| 轴 | 云台零偏转时与 {B} 对齐 |
| 偏转 | 由云台角 $(\alpha, \beta)$ 定义，见 §3.5 |

推力在 {T} 中恒沿 $+Z_T$：$\mathbf{F}^{thrust}_T = [0;\ 0;\ T]^T$。

---

## 2. 旋转约定

### 2.1 欧拉角 — ZYX 内旋

采用 **ZYX 内旋**（intrinsic）顺序，即先绕 $Z$ 旋转 yaw $\psi$，再绕新 $Y'$ 旋转 pitch $\theta$，最后绕新 $X''$ 旋转 roll $\varphi$。

旋转矩阵（机体系到惯性系）：

$$R_{IB}(\varphi, \theta, \psi) = R_z(\psi)\,R_y(\theta)\,R_x(\varphi)$$

其中基本旋转矩阵（右手正方向）：

$$R_x(\varphi) = \begin{bmatrix} 1 & 0 & 0 \\ 0 & \cos\varphi & -\sin\varphi \\ 0 & \sin\varphi & \cos\varphi \end{bmatrix}$$

$$R_y(\theta) = \begin{bmatrix} \cos\theta & 0 & \sin\theta \\ 0 & 1 & 0 \\ -\sin\theta & 0 & \cos\theta \end{bmatrix}$$

$$R_z(\psi) = \begin{bmatrix} \cos\psi & -\sin\psi & 0 \\ \sin\psi & \cos\psi & 0 \\ 0 & 0 & 1 \end{bmatrix}$$

**物理含义**（小角度近似）：

- $\varphi > 0$（roll）：机体向右倾（$Y_B$ 端下降）
- $\theta > 0$（pitch）：机头抬起（$X_B$ 端上升）
- $\psi > 0$（yaw）：机头向左偏

### 2.2 四元数 — Hamilton 标量在前

$$q = \begin{bmatrix} q_w \\ q_x \\ q_y \\ q_z \end{bmatrix}, \quad |q| = 1$$

四元数乘法遵循 Hamilton 约定（$ijk = -1$）。

四元数 $q$ 表示**机体系到惯性系**的旋转。旋转矩阵：

$$R_{IB}(q) = \begin{bmatrix}
1 - 2(q_y^2 + q_z^2) & 2(q_x q_y - q_w q_z) & 2(q_x q_z + q_w q_y) \\
2(q_x q_y + q_w q_z) & 1 - 2(q_x^2 + q_z^2) & 2(q_y q_z - q_w q_x) \\
2(q_x q_z - q_w q_y) & 2(q_y q_z + q_w q_x) & 1 - 2(q_x^2 + q_y^2)
\end{bmatrix}$$

向量变换：$\mathbf{v}_I = R_{IB}\,\mathbf{v}_B$。

### 2.3 欧拉角与四元数的转换

**欧拉角 → 四元数** (ZYX)：

$$q = q_z(\psi) \otimes q_y(\theta) \otimes q_x(\varphi)$$

展开：

$$\begin{aligned}
q_w &= c_\varphi c_\theta c_\psi + s_\varphi s_\theta s_\psi \\
q_x &= s_\varphi c_\theta c_\psi - c_\varphi s_\theta s_\psi \\
q_y &= c_\varphi s_\theta c_\psi + s_\varphi c_\theta s_\psi \\
q_z &= c_\varphi c_\theta s_\psi - s_\varphi s_\theta c_\psi
\end{aligned}$$

其中 $c_\varphi = \cos(\varphi/2)$，$s_\varphi = \sin(\varphi/2)$，余同。

**四元数 → 欧拉角**：

$$\begin{aligned}
\varphi &= \text{atan2}\!\big(2(q_w q_x + q_y q_z),\ 1 - 2(q_x^2 + q_y^2)\big) \\
\theta &= \arcsin\!\big(2(q_w q_y - q_z q_x)\big) \\
\psi &= \text{atan2}\!\big(2(q_w q_z + q_x q_y),\ 1 - 2(q_y^2 + q_z^2)\big)
\end{aligned}$$

### 2.4 欧拉角速率与机体角速度

$$\begin{bmatrix} \dot\varphi \\ \dot\theta \\ \dot\psi \end{bmatrix}
= W(\varphi, \theta)
\begin{bmatrix} \omega_x \\ \omega_y \\ \omega_z \end{bmatrix}$$

$$W = \begin{bmatrix}
1 & \sin\varphi\tan\theta & \cos\varphi\tan\theta \\
0 & \cos\varphi & -\sin\varphi \\
0 & \sin\varphi / \cos\theta & \cos\varphi / \cos\theta
\end{bmatrix}$$

在悬停点 $(\varphi = \theta = 0)$：$W = I_3$，即 $\dot\varphi \approx \omega_x$，$\dot\theta \approx \omega_y$，$\dot\psi \approx \omega_z$。

> **万向锁警告**：$\theta = \pm 90°$ 时 $W$ 奇异。仿真中使用四元数积分避免此问题，欧拉角仅用于显示和小角度线性化。

---

## 3. 非线性动力学方程

### 3.1 状态与输入定义

**状态向量**（13 维）：

$$\mathbf{x} = \begin{bmatrix} \mathbf{p}_I \\ \mathbf{v}_I \\ \mathbf{q} \\ \boldsymbol{\omega}_B \end{bmatrix}
= \begin{bmatrix} p_x \\ p_y \\ p_z \\ v_x \\ v_y \\ v_z \\ q_w \\ q_x \\ q_y \\ q_z \\ \omega_x \\ \omega_y \\ \omega_z \end{bmatrix}$$

| 分量 | 含义 | 坐标系 | 单位 |
|---|---|---|---|
| $\mathbf{p}_I$ | 位置 | 惯性系 | m |
| $\mathbf{v}_I$ | 速度 | 惯性系 | m/s |
| $\mathbf{q}$ | 姿态四元数 | — | — |
| $\boldsymbol{\omega}_B$ | 角速度 | 机体系 | rad/s |

**输入向量**（3 维）：

$$\mathbf{u} = \begin{bmatrix} T \\ \alpha \\ \beta \end{bmatrix}$$

| 分量 | 含义 | 单位 | 范围 |
|---|---|---|---|
| $T$ | 推力幅值 | N | $[T_{min},\ T_{max}]$ |
| $\alpha$ | 云台俯仰角 | rad | $[-\alpha_{lim},\ \alpha_{lim}]$ |
| $\beta$ | 云台滚转角 | rad | $[-\beta_{lim},\ \beta_{lim}]$ |

### 3.2 平动方程（牛顿第二定律）

$$m\,\dot{\mathbf{v}}_I = R_{IB}\,\mathbf{F}^{thrust}_B + m\,\mathbf{g}_I + \mathbf{F}^{dist}_I$$

$$\dot{\mathbf{p}}_I = \mathbf{v}_I$$

其中 $\mathbf{F}^{thrust}_B$ 为机体系下的推力矢量（见 §3.5），$\mathbf{F}^{dist}_I$ 为惯性系下的扰动力（风等，默认为零）。

### 3.3 转动方程（欧拉方程）

$$I_B\,\dot{\boldsymbol{\omega}}_B + \boldsymbol{\omega}_B \times (I_B\,\boldsymbol{\omega}_B) = \boldsymbol{\tau}^{thrust}_B + \boldsymbol{\tau}^{dist}_B$$

其中：

- $I_B = \text{diag}(I_{xx},\, I_{yy},\, I_{zz})$：绕 CG 的转动惯量（主轴，惯量积为零）
- $\boldsymbol{\tau}^{thrust}_B$：推力产生的力矩（见 §3.5）
- $\boldsymbol{\tau}^{dist}_B$：扰动力矩

展开：

$$\dot{\boldsymbol{\omega}}_B = I_B^{-1}\left(\boldsymbol{\tau}^{thrust}_B - \boldsymbol{\omega}_B \times (I_B\,\boldsymbol{\omega}_B)\right)$$

陀螺力矩展开形式（对角惯量）：

$$\boldsymbol{\omega}_B \times (I_B\,\boldsymbol{\omega}_B) = \begin{bmatrix}
(I_{zz} - I_{yy})\,\omega_y\,\omega_z \\
(I_{xx} - I_{zz})\,\omega_z\,\omega_x \\
(I_{yy} - I_{xx})\,\omega_x\,\omega_y
\end{bmatrix}$$

### 3.4 四元数运动学

$$\dot{\mathbf{q}} = \frac{1}{2}\,\Omega(\boldsymbol{\omega}_B)\,\mathbf{q}$$

其中 $\Omega$ 为 $4 \times 4$ 矩阵：

$$\Omega(\boldsymbol{\omega}) = \begin{bmatrix}
0 & -\omega_x & -\omega_y & -\omega_z \\
\omega_x & 0 & \omega_z & -\omega_y \\
\omega_y & -\omega_z & 0 & \omega_x \\
\omega_z & \omega_y & -\omega_x & 0
\end{bmatrix}$$

**推导**：此式等价于右乘形式 $\dot{q} = \frac{1}{2}\,q \otimes \bar{\omega}$，其中 $\bar{\omega} = [0;\ \omega_x;\ \omega_y;\ \omega_z]$ 为纯四元数。

**验证**：

- 当 $\boldsymbol{\omega} = \mathbf{0}$ 时，$\dot{\mathbf{q}} = \mathbf{0}$（静止无旋转）✓
- $\Omega$ 为反对称矩阵，保证 $\frac{d}{dt}|q|^2 = 2q^T\dot{q} = q^T \Omega q = 0$（范数守恒）✓

> 数值积分中仍需每步归一化 $q \leftarrow q / |q|$ 以抑制浮点误差累积。

### 3.5 推力矢量与力矩模型

#### 3.5.1 云台角定义与推力方向

云台角 $(\alpha, \beta)$ 将推力方向从 $+Z_B$ 偏转到空间方向。定义：

- $\alpha$ **（俯仰）**：推力在 $X_B\text{-}Z_B$ 平面内的偏转角。$\alpha > 0$ 使推力偏向 $+X_B$（前方）。
- $\beta$ **（滚转）**：推力在 $Y_B\text{-}Z_B$ 平面内的偏转角。$\beta > 0$ 使推力偏向 $+Y_B$（左方）。

推力方向单位向量（机体系）：

$$\boxed{\mathbf{d}_B(\alpha, \beta) = \begin{bmatrix} \sin\alpha \\ \sin\beta\,\cos\alpha \\ \cos\beta\,\cos\alpha \end{bmatrix}}$$

**验证**：

| 条件 | $\mathbf{d}_B$ | 物理含义 |
|---|---|---|
| $\alpha = \beta = 0$ | $[0;\ 0;\ 1]$ | 推力沿 $+Z_B$（正上方）✓ |
| $\alpha > 0,\ \beta = 0$ | $[\sin\alpha;\ 0;\ \cos\alpha]$ | 推力偏向 $+X_B$（前方）✓ |
| $\alpha = 0,\ \beta > 0$ | $[0;\ \sin\beta;\ \cos\beta]$ | 推力偏向 $+Y_B$（左方）✓ |
| 任意 $(\alpha, \beta)$ | $|\mathbf{d}_B| = 1$ | 单位向量 ✓ |

> **等价旋转矩阵表示**：$\mathbf{d}_B = R_{BT}\,\mathbf{e}_3$，其中 $R_{BT} = R_x(-\beta)\,R_y(\alpha)$，即先绕 $Y$ 轴旋转 $\alpha$，再绕 $X$ 轴旋转 $-\beta$。注意此处 $-\beta$ 是因为约定正 $\beta$ 偏向 $+Y_B$，而右手旋转 $R_x(\beta)$ 使 $+Z$ 偏向 $-Y$。

#### 3.5.2 推力矢量

机体系：

$$\mathbf{F}^{thrust}_B = T\,\mathbf{d}_B = T \begin{bmatrix} \sin\alpha \\ \sin\beta\,\cos\alpha \\ \cos\beta\,\cos\alpha \end{bmatrix}$$

惯性系（代入平动方程 §3.2）：

$$\mathbf{F}^{thrust}_I = R_{IB}\,\mathbf{F}^{thrust}_B$$

#### 3.5.3 推力产生的力矩

推力作用点相对 CG 的位置向量（机体系）：

$$\mathbf{r}_T = \begin{bmatrix} 0 \\ 0 \\ -l_T \end{bmatrix}_B$$

其中 $l_T > 0$ 为推力点到 CG 的距离。$\mathbf{r}_T$ 指向 $-Z_B$（推力点在 CG 下方），这是**倒立摆构型**的核心——重心在推力点之上。

力矩（机体系）：

$$\boldsymbol{\tau}^{thrust}_B = \mathbf{r}_T \times \mathbf{F}^{thrust}_B$$

展开叉乘：

$$\boldsymbol{\tau}^{thrust}_B = \begin{bmatrix} 0 \\ 0 \\ -l_T \end{bmatrix} \times T\begin{bmatrix} \sin\alpha \\ \sin\beta\cos\alpha \\ \cos\beta\cos\alpha \end{bmatrix}$$

$$\boxed{\boldsymbol{\tau}^{thrust}_B = T\,l_T \begin{bmatrix} \sin\beta\,\cos\alpha \\ -\sin\alpha \\ 0 \end{bmatrix}}$$

**验证**（小角度近似）：

$$\boldsymbol{\tau}^{thrust}_B \approx T\,l_T \begin{bmatrix} \beta \\ -\alpha \\ 0 \end{bmatrix}$$

| 输入 | 力矩 | 效果 |
|---|---|---|
| $\alpha > 0$ | $\tau_y < 0$ | 绕 $Y_B$ 负方向转矩 → 机头趋于下压 |
| $\beta > 0$ | $\tau_x > 0$ | 绕 $X_B$ 正方向转矩 → 机体趋于向右倾 |

> **偏航力矩为零**：$\tau_z = 0$，即单纯的云台偏转不产生偏航力矩。偏航控制需通过共轴双桨的转速差实现（本模型未包含，见 §3.7 备注）。

### 3.6 云台动力学（可选，一阶近似）

当需要仿真云台响应延迟时，引入一阶动力学：

$$\dot{\alpha}_{act} = \frac{\alpha_{cmd} - \alpha_{act}}{\tau_g}$$

$$\dot{\beta}_{act} = \frac{\beta_{cmd} - \beta_{act}}{\tau_g}$$

并施加限位：$|\alpha_{act}| \leq \alpha_{lim}$，$|\beta_{act}| \leq \beta_{lim}$。

当前仿真代码未启用此模块（假设云台响应为理想，$\alpha_{act} = \alpha_{cmd}$）。启用时需将状态向量扩展至 15 维。

### 3.7 完整 ODE 汇总

$$\dot{\mathbf{x}} = f(\mathbf{x}, \mathbf{u})$$

$$\begin{cases}
\dot{\mathbf{p}}_I = \mathbf{v}_I \\[4pt]
\dot{\mathbf{v}}_I = \dfrac{1}{m}\Big(R_{IB}(q)\,T\,\mathbf{d}_B(\alpha,\beta) + m\,\mathbf{g}_I\Big) \\[4pt]
\dot{\mathbf{q}} = \dfrac{1}{2}\,\Omega(\boldsymbol{\omega}_B)\,\mathbf{q} \\[4pt]
\dot{\boldsymbol{\omega}}_B = I_B^{-1}\Big(T\,l_T\begin{bmatrix}\sin\beta\cos\alpha \\ -\sin\alpha \\ 0\end{bmatrix} - \boldsymbol{\omega}_B \times (I_B\,\boldsymbol{\omega}_B)\Big)
\end{cases}$$

> **关于偏航控制**：当前模型有 3 个输入 $(T, \alpha, \beta)$，无法控制偏航。完整系统需引入第 4 个输入（共轴桨差速产生的偏航力矩 $\tau_{z,cmd}$）。在当前仿真中，偏航通道为开环，初始偏航速率将保持不变。

---

## 4. 参数表

所有参数以 `matlab/scripts/params.m` 为准，下表为当前取值。

### 4.1 刚体参数

| 符号 | 含义 | 单位 | 取值 |
|---|---|---|---|
| $m$ | 质量 | kg | 1.5 |
| $I_{xx}$ | $X_B$ 轴转动惯量 | kg·m² | 0.02 |
| $I_{yy}$ | $Y_B$ 轴转动惯量 | kg·m² | 0.02 |
| $I_{zz}$ | $Z_B$ 轴转动惯量 | kg·m² | 0.03 |
| $g$ | 重力加速度 | m/s² | 9.81 |

### 4.2 几何参数

| 符号 | 含义 | 单位 | 取值 |
|---|---|---|---|
| $l_T$ | 推力点到 CG 距离 | m | 0.15 |
| $\mathbf{r}_T$ | 推力点位置（机体系） | m | $[0;\ 0;\ -0.15]$ |

### 4.3 推进器参数

| 符号 | 含义 | 单位 | 取值 |
|---|---|---|---|
| $T_{hover}$ | 悬停推力 $= mg$ | N | 14.715 |
| $T_{max}$ | 最大推力 | N | $5 \times T_{hover}$ |
| $T_{min}$ | 最小推力 | N | $0.1 \times T_{hover}$ |

### 4.4 云台参数

| 符号 | 含义 | 单位 | 取值 |
|---|---|---|---|
| $\alpha_{lim}$ | 俯仰角限位 | rad | $\pm 25°$ |
| $\beta_{lim}$ | 滚转角限位 | rad | $\pm 25°$ |
| $\tau_g$ | 云台响应时间常数 | s | 0.05 |

---

## 5. 悬停平衡点与线性化

### 5.1 悬停平衡点

令 $\dot{\mathbf{x}} = \mathbf{0}$，求解平衡态：

$$\mathbf{x}_0 = \begin{bmatrix} \mathbf{p}_0 \\ \mathbf{0} \\ [1;0;0;0] \\ \mathbf{0} \end{bmatrix}, \quad \mathbf{u}_0 = \begin{bmatrix} mg \\ 0 \\ 0 \end{bmatrix}$$

物理含义：

- 位置任意（$\mathbf{p}_0$ 为任意悬停点）
- 速度为零
- 姿态为单位四元数（机体系与惯性系对齐）
- 角速度为零
- 推力等于重力，云台居中

**验证**：代入 ODE

- $\dot{\mathbf{p}} = \mathbf{0}$ ✓
- $m\dot{\mathbf{v}} = I \cdot mg \cdot [0;0;1] + m[0;0;-g] = [0;0;0]$ ✓
- $\dot{q} = \frac{1}{2}\Omega(\mathbf{0})q = \mathbf{0}$ ✓
- $\dot{\omega} = I_B^{-1}(mg \cdot l_T \cdot [0;0;0] - \mathbf{0}) = \mathbf{0}$ ✓

### 5.2 小扰动状态定义

在悬停点附近，用**欧拉角**替代四元数（避免四元数约束 $|q|=1$ 带来的冗余），定义 12 维扰动状态：

$$\delta\mathbf{x} = \begin{bmatrix} \delta p_x \\ \delta p_y \\ \delta p_z \\ \delta v_x \\ \delta v_y \\ \delta v_z \\ \delta\varphi \\ \delta\theta \\ \delta\psi \\ \delta\omega_x \\ \delta\omega_y \\ \delta\omega_z \end{bmatrix}, \quad \delta\mathbf{u} = \begin{bmatrix} \delta T \\ \delta\alpha \\ \delta\beta \end{bmatrix}$$

其中 $\delta T = T - mg$，$\delta\alpha = \alpha$，$\delta\beta = \beta$（平衡点处 $\alpha_0 = \beta_0 = 0$）。

### 5.3 线性化推导

在悬停点对 $\dot{\mathbf{x}} = f(\mathbf{x}, \mathbf{u})$ 做一阶 Taylor 展开：$\delta\dot{\mathbf{x}} = A\,\delta\mathbf{x} + B\,\delta\mathbf{u}$。

#### 5.3.1 位置运动学

$$\delta\dot{p}_x = \delta v_x, \quad \delta\dot{p}_y = \delta v_y, \quad \delta\dot{p}_z = \delta v_z$$

#### 5.3.2 平动方程线性化

原式：$m\dot{\mathbf{v}}_I = R_{IB}\,T\,\mathbf{d}_B + m\mathbf{g}_I$

小角度近似：

$$R_{IB} \approx I + [\boldsymbol{\epsilon}\times], \quad \boldsymbol{\epsilon} = \begin{bmatrix}\delta\varphi \\ \delta\theta \\ \delta\psi\end{bmatrix}$$

$$[\boldsymbol{\epsilon}\times] = \begin{bmatrix} 0 & -\delta\psi & \delta\theta \\ \delta\psi & 0 & -\delta\varphi \\ -\delta\theta & \delta\varphi & 0 \end{bmatrix}$$

平衡点处 $T_0\mathbf{d}_0 = mg\,[0;0;1]^T$，分别对姿态和输入求偏导：

**姿态变化的贡献**：

$$[\boldsymbol{\epsilon}\times] \cdot mg\begin{bmatrix}0\\0\\1\end{bmatrix} = mg\begin{bmatrix}\delta\theta \\ -\delta\varphi \\ 0\end{bmatrix}$$

**输入变化的贡献**（$\mathbf{d}_B$ 在平衡点的 Jacobian）：

$$\frac{\partial(T\mathbf{d}_B)}{\partial T}\bigg|_0 = \begin{bmatrix}0\\0\\1\end{bmatrix}, \quad \frac{\partial(T\mathbf{d}_B)}{\partial\alpha}\bigg|_0 = mg\begin{bmatrix}1\\0\\0\end{bmatrix}, \quad \frac{\partial(T\mathbf{d}_B)}{\partial\beta}\bigg|_0 = mg\begin{bmatrix}0\\1\\0\end{bmatrix}$$

合并（重力为常量不参与扰动）：

$$\boxed{\begin{aligned}
\delta\dot{v}_x &= g\,\delta\theta + g\,\delta\alpha \\
\delta\dot{v}_y &= -g\,\delta\varphi + g\,\delta\beta \\
\delta\dot{v}_z &= \frac{1}{m}\,\delta T
\end{aligned}}$$

**物理解读**：

- 机体前倾 ($\delta\theta > 0$，准确说是 pitch 指机头抬起，但此处 $R_{IB}$ 的偏导使 $\delta\theta$ 耦合到 $v_x$ 加速——这是因为 Z-up 惯性系下，机体 Z 轴偏离竖直后推力有水平分量) —— 更准确地说：当 pitch $\delta\theta$ 不为零时，推力有 $X_I$ 分量
- 机体左倾 ($\delta\varphi > 0$) 产生负 $Y_I$ 加速度
- 云台偏转 $\delta\alpha$、$\delta\beta$ 直接产生水平加速度

> **注意**：$\delta\dot{v}_y$ 中 $\delta\varphi$ 和 $\delta\beta$ 的符号反映了一个重要特性——机体倾斜和云台偏转对水平运动的贡献方向。当 $\delta\varphi > 0$（右倾），推力水平分量指向 $-Y_I$；当 $\delta\beta > 0$（推力偏向 $+Y_B$），水平力指向 $+Y_I$。

#### 5.3.3 姿态运动学线性化

在悬停点：$W(\varphi_0, \theta_0) = I_3$，故

$$\delta\dot\varphi = \delta\omega_x, \quad \delta\dot\theta = \delta\omega_y, \quad \delta\dot\psi = \delta\omega_z$$

#### 5.3.4 转动方程线性化

在悬停点 $\boldsymbol{\omega}_0 = \mathbf{0}$，陀螺项 $\omega \times (I\omega) = \mathbf{0}$。

力矩对输入的 Jacobian（由 §3.5.3）：

$$\frac{\partial\boldsymbol{\tau}^{thrust}_B}{\partial\alpha}\bigg|_0 = mg\,l_T\begin{bmatrix}0 \\ -1 \\ 0\end{bmatrix}, \quad \frac{\partial\boldsymbol{\tau}^{thrust}_B}{\partial\beta}\bigg|_0 = mg\,l_T\begin{bmatrix}1 \\ 0 \\ 0\end{bmatrix}, \quad \frac{\partial\boldsymbol{\tau}^{thrust}_B}{\partial T}\bigg|_0 = \begin{bmatrix}0\\0\\0\end{bmatrix}$$

推力幅值变化在 $\alpha_0 = \beta_0 = 0$ 时不改变力矩（力矩方向项为零）。

$$\boxed{\begin{aligned}
\delta\dot\omega_x &= \frac{mg\,l_T}{I_{xx}}\,\delta\beta \\
\delta\dot\omega_y &= -\frac{mg\,l_T}{I_{yy}}\,\delta\alpha \\
\delta\dot\omega_z &= 0
\end{aligned}}$$

### 5.4 状态空间矩阵

$$\delta\dot{\mathbf{x}} = A\,\delta\mathbf{x} + B\,\delta\mathbf{u}$$

状态排列：$\delta\mathbf{x} = [\delta p_x,\, \delta p_y,\, \delta p_z,\, \delta v_x,\, \delta v_y,\, \delta v_z,\, \delta\varphi,\, \delta\theta,\, \delta\psi,\, \delta\omega_x,\, \delta\omega_y,\, \delta\omega_z]^T$

输入排列：$\delta\mathbf{u} = [\delta T,\, \delta\alpha,\, \delta\beta]^T$

$$A = \begin{bmatrix}
\mathbf{0}_3 & I_3 & \mathbf{0}_3 & \mathbf{0}_3 \\
\mathbf{0}_3 & \mathbf{0}_3 & A_{v\phi} & \mathbf{0}_3 \\
\mathbf{0}_3 & \mathbf{0}_3 & \mathbf{0}_3 & I_3 \\
\mathbf{0}_3 & \mathbf{0}_3 & \mathbf{0}_3 & \mathbf{0}_3
\end{bmatrix}$$

其中姿态-速度耦合子块：

$$A_{v\phi} = \begin{bmatrix} 0 & g & 0 \\ -g & 0 & 0 \\ 0 & 0 & 0 \end{bmatrix}$$

$$B = \begin{bmatrix}
\mathbf{0}_3 & \mathbf{0}_3 & \mathbf{0}_3 \\
B_{vT} & B_{v\alpha} & B_{v\beta} \\
\mathbf{0}_3 & \mathbf{0}_3 & \mathbf{0}_3 \\
\mathbf{0}_3 & B_{\omega\alpha} & B_{\omega\beta}
\end{bmatrix}$$

展开为标量形式：

$$B = \begin{bmatrix}
0 & 0 & 0 \\
0 & 0 & 0 \\
0 & 0 & 0 \\
0 & g & 0 \\
0 & 0 & g \\
1/m & 0 & 0 \\
0 & 0 & 0 \\
0 & 0 & 0 \\
0 & 0 & 0 \\
0 & 0 & \dfrac{mg\,l_T}{I_{xx}} \\[4pt]
0 & -\dfrac{mg\,l_T}{I_{yy}} & 0 \\[4pt]
0 & 0 & 0
\end{bmatrix}$$

### 5.5 通道解耦

线性化系统**自然解耦**为三个独立子系统：

#### (a) 纵向通道（X-Pitch）

状态 $[\delta p_x,\ \delta v_x,\ \delta\theta,\ \delta\omega_y]$，输入 $\delta\alpha$：

$$A_x = \begin{bmatrix} 0&1&0&0 \\ 0&0&g&0 \\ 0&0&0&1 \\ 0&0&0&0 \end{bmatrix}, \quad B_x = \begin{bmatrix} 0 \\ g \\ 0 \\ -mg\,l_T/I_{yy} \end{bmatrix}$$

#### (b) 横向通道（Y-Roll）

状态 $[\delta p_y,\ \delta v_y,\ \delta\varphi,\ \delta\omega_x]$，输入 $\delta\beta$：

$$A_y = \begin{bmatrix} 0&1&0&0 \\ 0&0&-g&0 \\ 0&0&0&1 \\ 0&0&0&0 \end{bmatrix}, \quad B_y = \begin{bmatrix} 0 \\ g \\ 0 \\ mg\,l_T/I_{xx} \end{bmatrix}$$

#### (c) 高度通道（Z-Altitude）

状态 $[\delta p_z,\ \delta v_z]$，输入 $\delta T$：

$$A_z = \begin{bmatrix} 0&1 \\ 0&0 \end{bmatrix}, \quad B_z = \begin{bmatrix} 0 \\ 1/m \end{bmatrix}$$

#### (d) 偏航通道（Yaw，不可控）

状态 $[\delta\psi,\ \delta\omega_z]$，无输入：

$$A_\psi = \begin{bmatrix} 0&1 \\ 0&0 \end{bmatrix}, \quad B_\psi = \begin{bmatrix} 0 \\ 0 \end{bmatrix}$$

偏航通道在当前 3 输入模型下**不可控**，需引入第 4 个输入（偏航力矩）。

---

## 6. 系统分析

### 6.1 开环特征值与稳定性

矩阵 $A$ 的特征值全部为零（$\det(sI - A) = s^{12}$）。

**物理解释**：

对自由飞行刚体，重力不在 CG 产生力矩，因此不存在类似经典固定支点倒立摆的指数不稳定（$e^{at}$ 型发散）。然而，系统是**边际不稳定**的：

1. 任何初始姿态偏差 $\delta\theta_0 \neq 0$ 会导致持续的水平加速度 $\delta\dot{v}_x = g\,\delta\theta_0$，水平速度线性增长
2. 任何初始角速度 $\delta\omega_{y,0} \neq 0$ 会导致姿态线性增长，进而水平加速度二次增长
3. 综合效果：无控制时，位置偏差随时间多项式增长（$t^2$ 到 $t^4$ 阶）

这种"多重积分器链"结构虽非指数不稳定，但在实际中**必须闭环控制**——任何微小扰动都会导致位置无界漂移。

> **与经典倒立摆的区别**：经典倒立摆（如杆铰接于小车上）的 $A$ 矩阵包含 $\sqrt{g/l}$ 的不稳定特征值，因为支点约束力产生了关于铰接点的重力力矩。本系统为自由飞行体，无此约束。

### 6.2 可控性分析

对 10 维可控子系统（排除偏航通道）检查可控性矩阵。

**纵向通道**：

$$\mathcal{C}_x = [B_x,\ A_x B_x,\ A_x^2 B_x,\ A_x^3 B_x]$$

$$= \begin{bmatrix}
0 & g & 0 & -mg^2 l_T/I_{yy} \\
g & 0 & -mg^2 l_T/I_{yy} & 0 \\
0 & -mgl_T/I_{yy} & 0 & 0 \\
-mgl_T/I_{yy} & 0 & 0 & 0
\end{bmatrix}$$

$$\det(\mathcal{C}_x) = \left(\frac{mgl_T}{I_{yy}}\right)^2 \cdot g^2 \cdot \left(\frac{mgl_T}{I_{yy}}\right)^2 \neq 0$$

**秩 = 4**，完全可控 ✓。

**横向通道**：对称结构，同理秩 = 4，完全可控 ✓。

**高度通道**：$\mathcal{C}_z = [B_z,\ A_z B_z] = \begin{bmatrix} 0 & 1/m \\ 1/m & 0 \end{bmatrix}$，秩 = 2 ✓。

**结论**：10 维子系统 $[\delta p_x, \delta v_x, \delta\theta, \delta\omega_y, \delta p_y, \delta v_y, \delta\varphi, \delta\omega_x, \delta p_z, \delta v_z]$ 由 $[\delta T, \delta\alpha, \delta\beta]$ 完全可控。偏航通道 $[\delta\psi, \delta\omega_z]$ 在当前模型下不可控。

### 6.3 数值验证

代入参数值：$m = 1.5$，$g = 9.81$，$l_T = 0.15$，$I_{xx} = I_{yy} = 0.02$，$I_{zz} = 0.03$。

$$\frac{mg\,l_T}{I_{xx}} = \frac{1.5 \times 9.81 \times 0.15}{0.02} = 110.36\ \text{rad/s}^2$$

$$\frac{mg\,l_T}{I_{yy}} = 110.36\ \text{rad/s}^2$$

纵向通道 $B_x = [0;\ 9.81;\ 0;\ -110.36]^T$。

高度通道 $B_z = [0;\ 0.667]^T$。

### 6.4 可观性（简要）

若传感器提供完整状态（IMU + 位置传感器），则系统完全可观。实际飞控中：

- IMU 直接测量 $\boldsymbol{\omega}_B$ 和加速度
- 姿态由 IMU 数据融合估计
- 位置/速度可由气压计（$z$）、光流/GPS（$x, y$）提供

可观性矩阵的详细分析留待状态估计器设计阶段。

---

## 7. 现有代码诊断

基于上述严格推导，逐一检查现有 MATLAB 代码的正确性。

### 7.1 `thrust_model.m` — 推力方向向量

**代码**（第 20-21 行）：

```matlab
% 俯仰 alpha 绕 Y，滚转 beta 绕 X：d_body = R_x(beta)*R_y(alpha)*[0;0;1]
d_body = [sa; sb*ca; cb*ca];
```

**诊断**：

- **公式正确**：`d_body = [sin(α); sin(β)cos(α); cos(β)cos(α)]` 与本文档 §3.5.1 定义一致 ✅
- **注释错误**：注释写 `R_x(beta)*R_y(alpha)`，但正确的旋转矩阵表示为 $R_x(-\beta) \cdot R_y(\alpha)$（注意 $-\beta$）。标准右手旋转 $R_x(\beta)$ 使 $+Z$ 偏向 $-Y$，而我们约定正 $\beta$ 偏向 $+Y$，故实际是 $R_x(-\beta)$。注释需修正。 ⚠️

### 7.2 `rigid_body_ode.m` — 四元数运动学

**代码**（第 29-33 行）：

```matlab
Om = [0,    -omega(1), -omega(2), -omega(3);
      omega(1), 0,       omega(3), -omega(2);
      omega(2), -omega(3), 0,       omega(1);
      omega(3),  omega(2), -omega(1), 0];
q_dot = 0.5 * Om * q;
```

**诊断**：与本文档 §3.4 中 $\Omega(\omega)$ 矩阵**完全一致** ✅。

### 7.3 `quat2rotm.m` — 旋转矩阵

**代码**注释 "body to inertial, v_I = R * v_B"，公式为标准 Hamilton 四元数旋转矩阵。

**诊断**：与本文档 §2.2 **完全一致** ✅。

### 7.4 `euler2quat.m` 与 `quat2euler.m`

**诊断**：两函数实现 ZYX 内旋约定的标准公式，与本文档 §2.3 **一致** ✅。

### 7.5 `attitude_controller.m` — 控制分配符号

**代码**（第 41-48 行）：

```matlab
d = abs(p.r_thrust(3));
T_use = max(T, 1e-6);
alpha = -tau_des(2) / (T_use * d);
beta  =  tau_des(1) / (T_use * d);
```

**诊断**：

由 §3.5.3 的小角度近似：

$$\tau_x \approx T\,l_T\,\beta \implies \beta = \frac{\tau_x}{T\,l_T}$$
$$\tau_y \approx -T\,l_T\,\alpha \implies \alpha = -\frac{\tau_y}{T\,l_T}$$

代码中 `d = abs(r_thrust(3)) = l_T`，所以：
- `alpha = -tau_des(2)/(T*l_T)` ↔ $\alpha = -\tau_y / (T\,l_T)$ ✅
- `beta = tau_des(1)/(T*l_T)` ↔ $\beta = \tau_x / (T\,l_T)$ ✅

控制分配符号**正确** ✅。

### 7.6 `thrust_dir_to_att.m` — 推力方向到期望姿态

**代码**（第 15-16 行）：

```matlab
pitch_des = atan2(dx, dz);   % 推力 +x 需 pitch>0
roll_des  = atan2(-dy, dz);  % 推力 +y 需 roll<0
```

**诊断**：

由 §2.1，机体 $Z_B$（推力默认方向）在惯性系中为：

$$\mathbf{z}_{B,I} = R_{IB}\begin{bmatrix}0\\0\\1\end{bmatrix} = \begin{bmatrix} \sin\theta\cos\varphi \\ -\sin\varphi \\ \cos\theta\cos\varphi \end{bmatrix}$$

若期望推力方向为 $\mathbf{d}_I = [d_x; d_y; d_z]$，则：

$$\theta = \text{atan2}(d_x,\, d_z) \quad (\text{精确需 } d_z = \cos\theta\cos\varphi, \text{ 此处近似 } \varphi \approx 0)$$

$$\varphi = \arcsin(-d_y) \quad (\text{精确值})$$

代码使用 `atan2(-dy, dz)` 而非 $\arcsin(-d_y)$。两者在 $\theta \approx 0$（即 $d_z \approx \cos\varphi$）时近似相等，但当 $\theta$ 较大时有偏差。

- **近悬停使用**：误差可忽略 ✅
- **大角度使用**：存在偏差，建议改用 $\varphi = \arcsin(\text{clamp}(-d_y, -1, 1))$ ⚠️

### 7.7 `position_controller.m` — 推力方向推导

**代码**（第 33 行）：

```matlab
F_des = p.m * (a_des - g_vec);
```

**诊断**：

由 $m\dot{\mathbf{v}}_I = \mathbf{F}^{thrust}_I + m\mathbf{g}_I$ 得 $\mathbf{F}^{thrust}_I = m(\mathbf{a}_{des} - \mathbf{g}_I)$。

代码中 `g_vec = [0; 0; -g]`，所以 `a_des - g_vec = a_des - [0;0;-g] = a_des + [0;0;g]`。

即 $\mathbf{F}_{des} = m(\mathbf{a}_{des} + [0;0;g])$。对于悬停（$a_{des} = 0$），$F_{des} = [0;0;mg]$，推力向上。✅

### 7.8 综合诊断总结

| 文件 | 状态 | 问题 |
|---|---|---|
| `rigid_body_ode.m` | ✅ 正确 | — |
| `thrust_model.m` | ⚠️ 注释错误 | 注释写 `R_x(beta)` 应为 `R_x(-beta)` |
| `quat2rotm.m` | ✅ 正确 | — |
| `euler2quat.m` | ✅ 正确 | — |
| `quat2euler.m` | ✅ 正确 | — |
| `attitude_controller.m` | ✅ 正确 | 控制分配符号一致 |
| `thrust_dir_to_att.m` | ⚠️ 近似 | 大角度下 roll 提取不精确 |
| `position_controller.m` | ✅ 正确 | — |

### 7.9 稳定性问题可能原因

代码本身的方程和符号在小角度范围内是一致且正确的。当前仿真出现发散/不合理响应的可能原因：

1. **PID 参数整定不当**：缺乏系统化设计方法，当前参数为手工试凑
   - 内环带宽：$\omega_{rate} \approx \sqrt{K_p^{rate} \cdot mg\,l_T / I} \approx \sqrt{0.08 \times 110.36} \approx 3.0\ \text{rad/s}$，对应 $\sim 0.5\ \text{Hz}$
   - 对于倒立摆系统，这个带宽可能不足以快速稳定姿态
   
2. **cascaded PID 带宽不匹配**：外环（姿态角 PID）和内环（角速度 PID）的带宽比应至少 3–5 倍，需验证
   
3. **积分项累积**：在大偏差场景下，积分项可能饱和或引起振荡
   
4. **大角度偏差**：`thrust_dir_to_att` 的近似在大角度下偏差，导致外环指令不准确

5. **无云台动力学**：理想云台（无延迟）与实际控制器设计不匹配，可能导致增益选择偏激进

**建议的后续行动**：

1. 基于 §5 的线性化模型设计 LQR 控制器，获得理论最优增益作为 baseline
2. 检查纵向/横向通道的频率响应和闭环带宽
3. 添加云台一阶动力学，评估其对稳定性裕度的影响
4. 从小扰动场景开始验证，逐步增大初始偏差

---

## 附录 A：符号总表

| 符号 | 含义 | 单位 | 所属坐标系 |
|---|---|---|---|
| $\mathbf{p}_I = [p_x, p_y, p_z]^T$ | 位置 | m | {I} |
| $\mathbf{v}_I = [v_x, v_y, v_z]^T$ | 速度 | m/s | {I} |
| $\mathbf{q} = [q_w, q_x, q_y, q_z]^T$ | 姿态四元数 | — | — |
| $\boldsymbol{\omega}_B = [\omega_x, \omega_y, \omega_z]^T$ | 角速度 | rad/s | {B} |
| $\varphi, \theta, \psi$ | 欧拉角（roll, pitch, yaw） | rad | — |
| $T$ | 推力幅值 | N | 标量 |
| $\alpha$ | 云台俯仰角 | rad | — |
| $\beta$ | 云台滚转角 | rad | — |
| $\mathbf{d}_B$ | 推力方向单位向量 | — | {B} |
| $\mathbf{r}_T$ | 推力点相对 CG 位置 | m | {B} |
| $l_T$ | 推力点到 CG 距离 | m | 标量 |
| $m$ | 机体质量 | kg | — |
| $I_B = \text{diag}(I_{xx}, I_{yy}, I_{zz})$ | 转动惯量 | kg·m² | {B} |
| $R_{IB}$ | 机体到惯性旋转矩阵 | — | — |
| $\tau_g$ | 云台时间常数 | s | — |
| $A, B$ | 线性化状态空间矩阵 | — | — |

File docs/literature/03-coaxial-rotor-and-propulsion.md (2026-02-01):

# 共轴旋翼与推进器建模 — 文献摘编

DroneX 采用**共轴反桨**推进，向下产生推力并自然抵消反扭矩；建模需考虑上下桨干扰、拉力/扭矩与转速关系，供仿真与控制分配使用。

---

## 1. 与 DroneX 的对应关系

| 主题 | 在项目中的作用 |
|---|---|
| 单桨拉力/扭矩与转速 | 推力 T = f(Ω)，扭矩 Q = g(Ω)，用于控制分配与仿真 |
| 共轴双桨干扰 | 下桨处于上桨尾流中，效率系数、干扰系数 |
| 反扭矩抵消 | 上下桨反转，总反扭矩近似为零，偏航可另用转速差或扩展方案 |

---

## 2. 推荐文献要点

### 2.1 旋翼气动基础（Leishman）

- **书名**：*Principles of Helicopter Aerodynamics*  
- **与项目关系**：桨叶气动、拉力与扭矩系数 C_T、C_Q，以及雷诺数、马赫数修正。
- **可借鉴**：  
  - 拉力：T = ρ A (Ω R)² C_T，扭矩：Q = ρ A (Ω R)² R C_Q。  
  - 共轴时上、下桨的 C_T、C_Q 受干扰影响，常通过试验或高 fidelity 仿真得到修正系数。

### 2.2 共轴旋翼综述（Coleman, NASA TM 3675）

- **题目**：A Survey of Theoretical and Experimental Coaxial Rotor Aerodynamic Research  
- **与项目关系**：共轴布局的轴向间距、桨盘重叠、上下桨功率分配与效率。
- **可借鉴**：  
  - 上下桨间距与干扰系数：间距过小效率损失大，过大则结构与重量不利。  
  - 工程上常用“干扰系数”k：T_coax ≈ k · (T_upper + T_lower)，k < 1，需结合桨型与间距标定。

### 2.3 共轴 + 倾转（Kim 等）

- **题目**：Design and Implementation of a Coaxial Quadrotor with Tiltable Rotors  
- **与项目关系**：共轴与推力矢量（倾转）结合，与 DroneX“共轴 + 二轴云台”在功能上类似。
- **可借鉴**：  
  - 推力矢量与共轴单元的机械布局、重心与推力点相对位置。  
  - 控制分配中“总推力幅值 + 推力方向”的分解方式。

### 2.4 直升机性能与稳定性（Prouty）

- **书名**：*Helicopter Performance, Stability, and Control*  
- **与项目关系**：旋翼推力/扭矩与转速、总距的实用关系，便于建立简化仿真模型。
- **可借鉴**：  
  - 在悬停与小速度范围内，T ∝ Ω² 的近似；电调/电机响应延迟可建模为一阶环节。  
  - 仿真中推进器子模块：输入为转速或油门指令，输出为 T 和 Q（若需偏航力矩）。

---

## 3. 与 PLAN.md 的衔接

- **推进方式**：共轴反桨，向下推力，自然抵消反扭矩；偏航可通过共轴双桨转速差或后续扩展实现。  
- **仿真子系统**：推进器模型需包含“推力–转速关系、共轴干扰系数”；云台动力学为俯仰+滚转二轴、电机响应与机械限位。  
- **控制分配**：期望力/力矩 → 推力幅值 T + 云台角 (α, β)；T 由转速或油门指令给出，需与推进器模型一致。

---

## 4. 建模建议

- **最小可用模型**：T = k_T · Ω²，Q = k_Q · Ω²，共轴时 T_total = k_coax · (T_upper + T_lower)，k_coax 由试验或文献初值（如 0.85–0.95）选取后标定。  
- **桨叶数据**：UIUC/NACA/APC 等公开桨叶数据可用于估算 C_T、C_Q 和雷诺数修正，再换算到本机桨径与转速范围。

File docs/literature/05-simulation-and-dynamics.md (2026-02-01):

# 仿真与动力学建模 — 文献摘编

支持 DroneX **仿真子系统**（MATLAB/Simulink）中的刚体动力学、坐标系约定、推进器与云台模型，以及控制器在环仿真 (CIL)。

---

## 1. 与 DroneX 的对应关系

| 主题 | 在项目中的作用 |
|---|---|
| 坐标系与姿态表示 | 惯性系（地面、Z 向上）、机体系（重心）、推力/云台系，与 PLAN.md 一致 |
| 平动方程 | m·a = F_thrust + m·g + F_disturbance |
| 转动方程 | I·ω̇ + ω×(I·ω) = τ_thrust + τ_disturbance |
| 推进器与云台模型 | 推力 T(Ω)、共轴干扰；云台角 (α, β) 与电机动力学、限位 |
| CIL | 与真实控制器代码或等价逻辑在环，验证参数与鲁棒性 |

---

## 2. 推荐文献要点

### 2.1 飞行器动力学建模与仿真（Zipfel）

- **书名**：*Modeling and Simulation of Aerospace Vehicle Dynamics*  
- **与项目关系**：六自由度刚体方程、不同坐标系（NED/ENU/体轴）的定义与转换，以及欧拉角/四元数微分。
- **可借鉴**：  
  - 惯性系下位置/速度微分；体轴系下角速度与欧拉角速率关系。  
  - 转动惯量矩阵 I 在体轴系下的常数假设；外力/力矩在体轴系下的表达。  
  - 与 PLAN.md 中“惯性系 Z 向上、机体系原点在重心”的约定对应。

### 2.2 刚体与多体动力学（Jazar）

- **书名**：*Advanced Dynamics*  
- **与项目关系**：欧拉角奇异点（万向锁）、四元数微分方程与归一化，多体系统中铰链与约束。
- **可借鉴**：  
  - 俯仰角 θ 接近 ±90° 时欧拉角速率退化，仿真中建议用四元数积分。  
  - 云台相对机体的转动可建模为多体铰链（俯仰轴、滚转轴），若用 Simscape Multibody 可对应为 Revolute 关节。

### 2.3 Aerospace Blockset / Simscape（MathWorks）

- **与项目关系**：PLAN.md 指定 MATLAB（含 Simulink）为仿真工具，可选 Simscape Multibody 做机械/接触。
- **可借鉴**：  
  - **Aerospace Blockset**：6DoF 刚体块、重力、风模型；自定义推力/力矩接口接推进器+云台模型。  
  - **Simscape Multibody**：机架、云台、推进单元为刚体，铰链与驱动；适合校核机构与耦合动力学。  
  - 控制器在环：Simulink 中嵌入与飞控等价的离散控制器（或自动生成 C 代码做 SIL）。

### 2.4 四旋翼 Simulink 建模（Luukkonen, Aalto）

- **题目**：Modelling and Control of Quadcopter  
- **与项目关系**：完整的 Simulink 框图、参数表、线性化与控制器设计，流程可迁移到 TVC 无人机。
- **可借鉴**：  
  - 状态变量选取：位置、速度、姿态（四元数或欧拉角）、角速度。  
  - 推进器子块：指令 → 推力/力矩；在 DroneX 中改为 T + (α, β) → F_thrust, τ_thrust。  
  - 验证标准：阶跃响应、稳定裕度、扰动抑制。

### 2.5 坐标系与标准

- **NED / ENU**：惯性系 Z 向上即 ENU 一类；文献与仿真中需统一符号（如 X 前、Y 左、Z 上）。  
- **PLAN.md**：惯性系地面固定 Z 向上；机体系原点在重心；推力系随云台偏转。建议在仿真文档中写清各系定义与转换矩阵。

---

## 3. 与 PLAN.md 的衔接

- **仿真子系统**：刚体动力学、推进器（推力–转速、共轴干扰）、云台动力学（俯仰+滚转、电机响应、限位）、CIL；可选 Simscape Multibody。  
- **输出**：验证过的控制参数、轨迹规划结果。  
- **开发阶段 P0**：动力学推导、仿真环境搭建、控制器初步验证 → 仿真报告、控制参数初值。

---

## 4. 仿真实现建议

- **状态向量**：位置 p（惯性系）、速度 v（惯性系或体轴）、四元数 q、角速度 ω（体轴）；微分方程见 Zipfel/Stevens。  
- **推力与力矩**：由 T 和云台角 (α, β) 得到 F_thrust 在体轴系下的分量，再算 τ_thrust = r_cp × F_thrust；r_cp 为推力作用点在体轴系下相对重心的位置。  
- **云台模型**：二阶或一阶+限位，输入为期望 (α_d, β_d)，输出为实际 (α, β)；与真实电机带宽一致便于 CIL 可信度。  
- **验证**：悬停平衡、阶跃姿态/位置、风扰动、降落段轨迹；与后续实机 P2–P4 阶段对照。

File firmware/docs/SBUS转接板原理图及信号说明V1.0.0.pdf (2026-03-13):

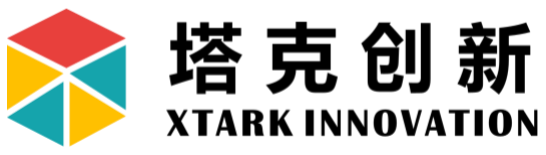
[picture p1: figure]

SBUS 转 UART 串口转接板说明手册

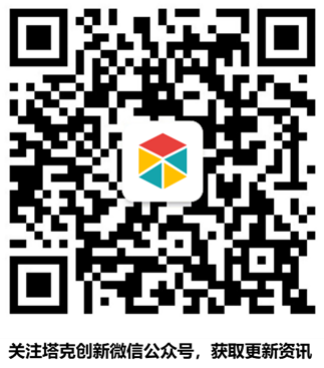
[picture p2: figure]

塔克 创新 官网 | www.xtark.cn | 1 / 5

# 烟台塔克电子科技有限公司

# SBUS 转 UART 串口转接板

# 说 明 手 册

V1.0

版权申明

本手册版权归属塔克创新所有，并保留一切权力，受法律保护。非经(书面形式)同意，任何单 位及个人不得擅自摘录或修改本手册部分或全部内容，违者我们将追究其法律责任。

版本说明

版本 | 日期 | 内容说明
V1.0 | 2024/9/18 | 第一次发布

塔克媒体

塔克官网 | www.xtark.cn
淘宝店铺 | https://xtark.taobao.com (https://shop246676508.taobao.com/)
塔克哔哩 | https://space.bilibili.com/511052131
销售邮箱 | sales@xtark.cn

部分知识科普内容整理自网络，部分为 AI 生成，如有侵权，请告知。

## 1. SBUS 协议介绍

SBUS 是 FUTABA 提出的舵机控制总线，全称 Serial Bus，别名 S-BUS 或 SBUS，也称

Futaba SBUS。它就是基于串口反电平逻辑的传输方式。。

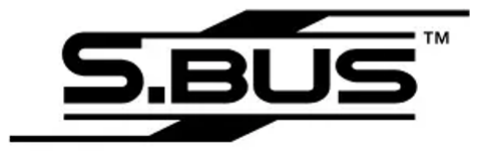
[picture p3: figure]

波特率为 100Kps, 8 位数据位，偶校验，2 位停止位，无流控。每帧 25 个字节，帧格式如

下。

[数据头] [第 1 字节] [第 2 字节] ......[第 22 的字节] [标志位] [数据尾]

数据头、标志位、数据尾 不携带信息，而且数据头和数据尾是固定的，数据头=0x0f; 数据尾

=0x00;

数据头（1 字节）+数据（22 字节）+标志位（1 字节）+数据尾（1 字节）

中间 22 个数据字节为 16 个通道的数据，每个通道用 11 bit 表示，范围是 0-2047。

因为遥控接收模块出来的电平信号跟普通串口逻辑是反逻辑，所以还需要下面这个电平转换电 路。

## 2. 转换电路

转接板电平转换电路如下图所示。

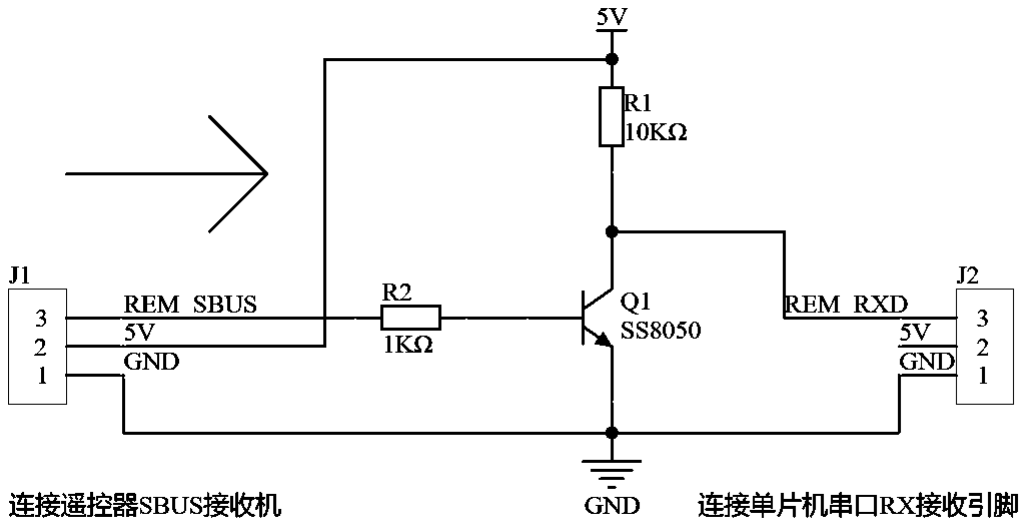
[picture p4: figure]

## 3. 读取说明

100K 的波特率不是标准波特率，一般串口工具都不能直接读取（所以不要直接用电脑调试， (https://so.csdn.net/so/search?q=%E6%B3%A2%E7%89%B9%E7%8E%87&spm=1001.2101.3001.7020) 除非你的电脑写好了非标准串口），可以用单片机读取。

## 4. 编码原理

一个信息是二进制的 11bit，比如 1111 1111 111 就可以表示一个信息，一共 16 个这样的 信息，按照顺序将这 16 个信息依次排成一串，得到一个 176bit（11 *16）的数据，也就是 22 字 节（176 / 8 = 22）的数据，再加上数据头数据尾校验位就组成了一个要通过串口传送的信息。每 隔 4 或者 14ms 就传送一个这样的信息。

所以这 16 个信息每一个所能表示的最大值是 2^11 = 2048，也就是他的精度。

## 5. 标志位说明

标志位的高四位有特殊含义，第四位并没有使用，依照我的理解，第七位和第六位表示两个数 字通道（通道 17 和 18）信息（就是只有高低电平的通道，一般用来控制通断或者某个电机简单的 启动或者停止，比如 1 表示启动电机 0 表示停止电机），第五位表示帧丢失，接收机红色 LED 亮 起，我的理解是，如果这一位为 1，表示这一帧信号出问题了，接收机红色 LED 亮起。第四位表示 故障保护激活，意思应该是说如果这一位为 1，激活接受方故障保护。

bit7 = ch17 = digital channel (0x80)

bit6 = ch18 = digital channel (0x40)

bit5 = Frame lost, equivalent red LED on receiver (0x20)

bit4 = failsafe activated (0x10)

bit3 = n/a

bit2 = n/a

bit1 = n/a

bit0 = n/a

## 6. 解码代码

buffer[]对应接收到的数据，_channels[]对应通道。解码代码如下

_channels[0] = (buffer[1] (buffer[1]|buffer[2]<<8) | & 0x07FF);
_channels[1] = ((buffer[2]>>3 |buffer[3]<<5) | & 0x07FF);

_channels[2] = ((buffer[3]>>6 |buffer[4]<<2 |buffer[5]<<10) & 0x07FF);

_channels[3] = ((buffer[5]>>1 |buffer[6]<<7) | & 0x07FF);
_channels[4] = ((buffer[6]>>4 |buffer[7]<<4) | & 0x07FF);
_channels[5] = ((buffer[7]>>7 |buffer[8]<<1 |buffer[9]<<9) | & 0x07FF);
_channels[6] = ((buffer[9]>>2 |buffer[10]<<6) | & 0x07FF);
_channels[7] = ((buffer[10]>>5|buffer[11]<<3) | & 0x07FF);
_channels[8] = ((buffer[12] | |buffer[13]<<8) | & 0x07FF);
_channels[9] = ((buffer[13]>>3|buffer[14]<<5) | & 0x07FF);

_channels[10] = ((buffer[14]>>6|buffer[15]<<2|buffer[16]<<10) & 0x07FF);

_channels[11] = ((buffer[16]>>1|buffer[17]<<7) | & 0x07FF);
_channels[12] = ((buffer[17]>>4|buffer[18]<<4) | & 0x07FF);

_channels[13] = ((buffer[18]>>7|buffer[19]<<1|buffer[20]<<9) & 0x07FF);

_channels[14] = ((buffer[20]>>2|buffer[21]<<6) | & 0x07FF);
_channels[15] = ((buffer[21]>>5|buffer[22]<<3) | & 0x07FF);

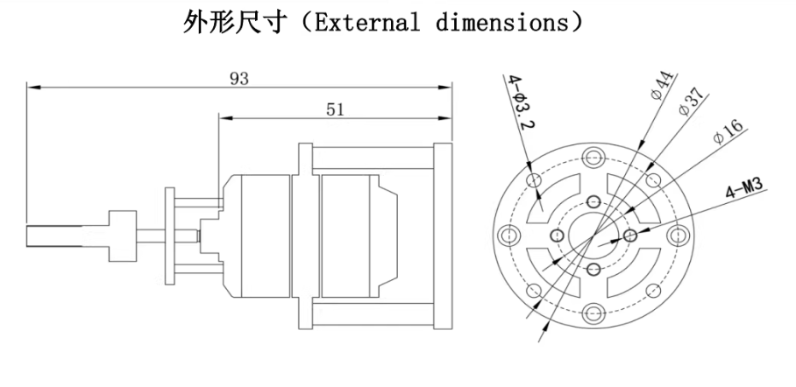
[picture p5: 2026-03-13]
mechanical/docs/尺寸/电机.png

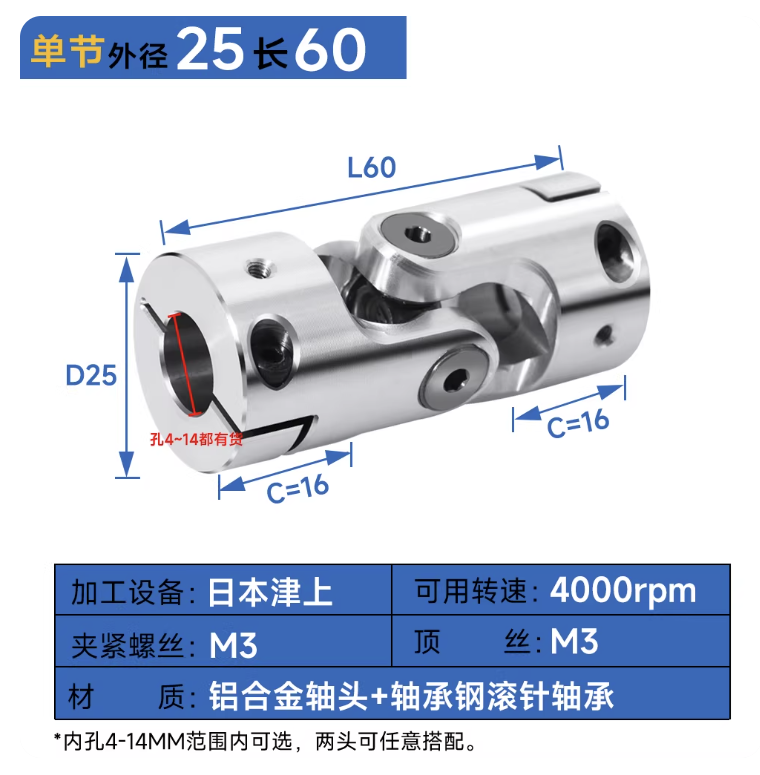
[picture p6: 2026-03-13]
mechanical/docs/尺寸/万向节.png

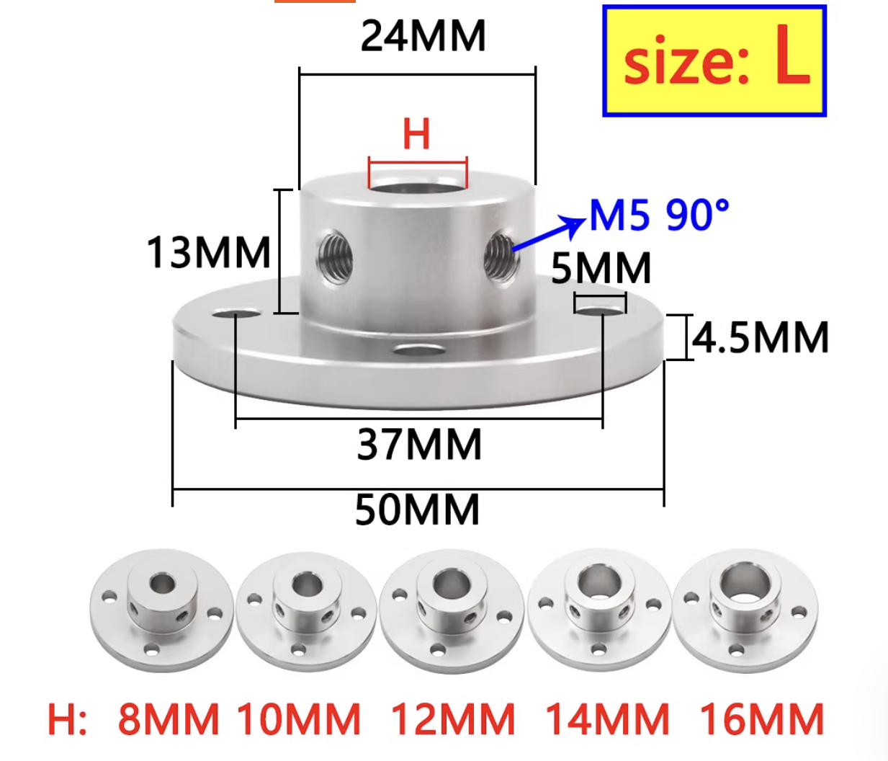
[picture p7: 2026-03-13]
mechanical/docs/尺寸/法兰座.png

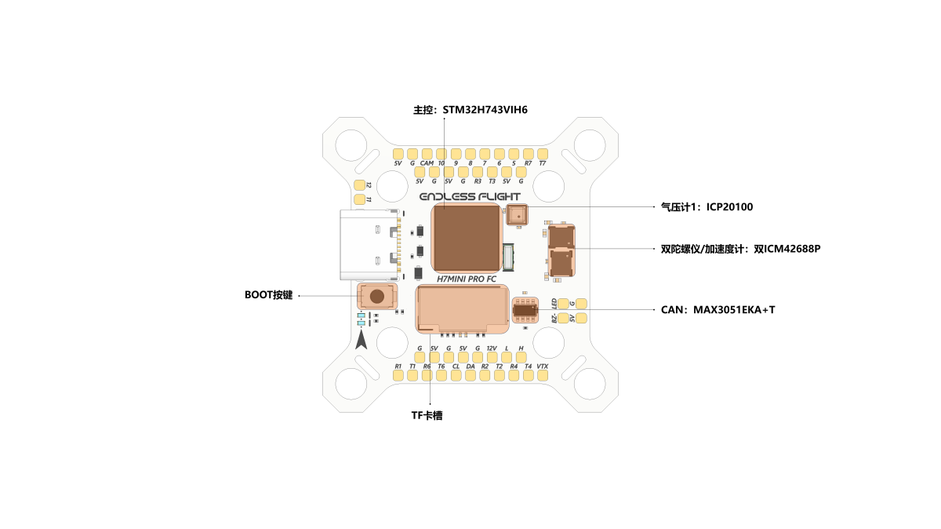
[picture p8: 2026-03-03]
firmware/docs/FC_PORT3.png

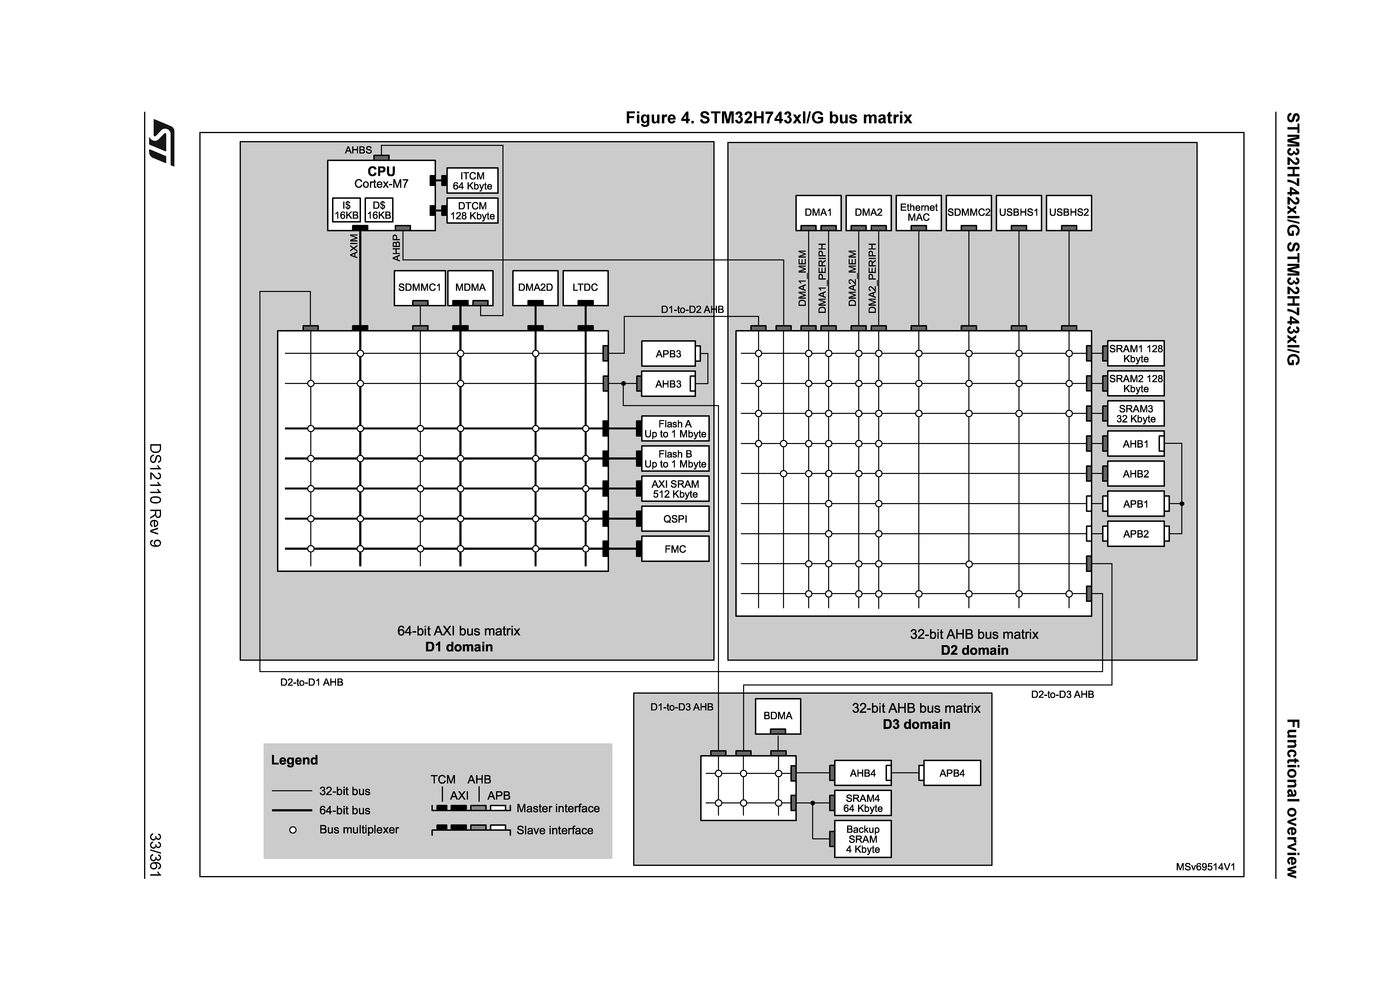
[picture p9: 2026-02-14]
firmware/docs/总线矩阵.jpg

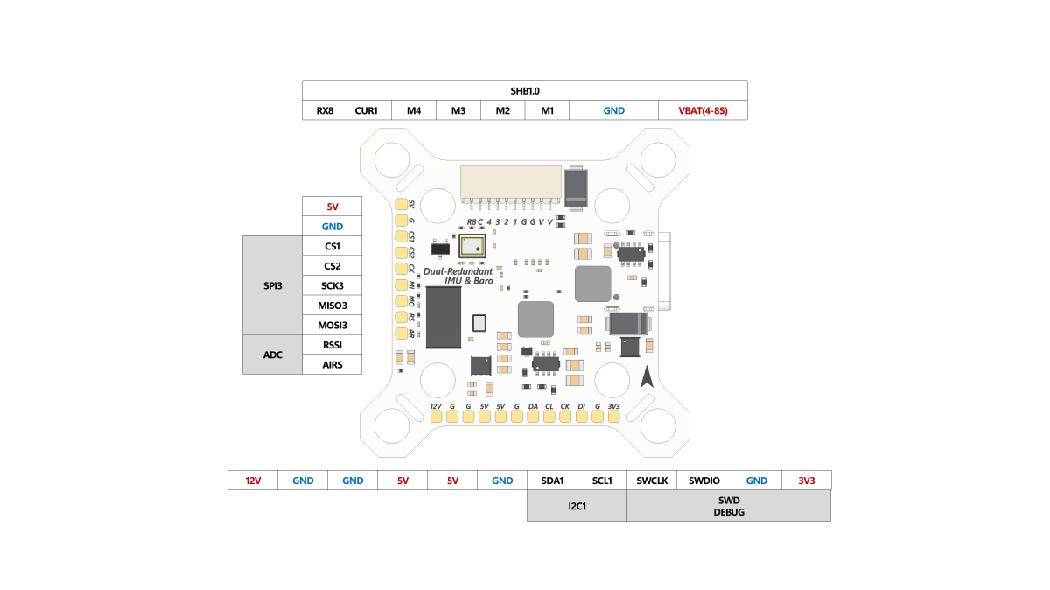
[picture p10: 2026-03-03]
firmware/docs/FC_PORT2.png

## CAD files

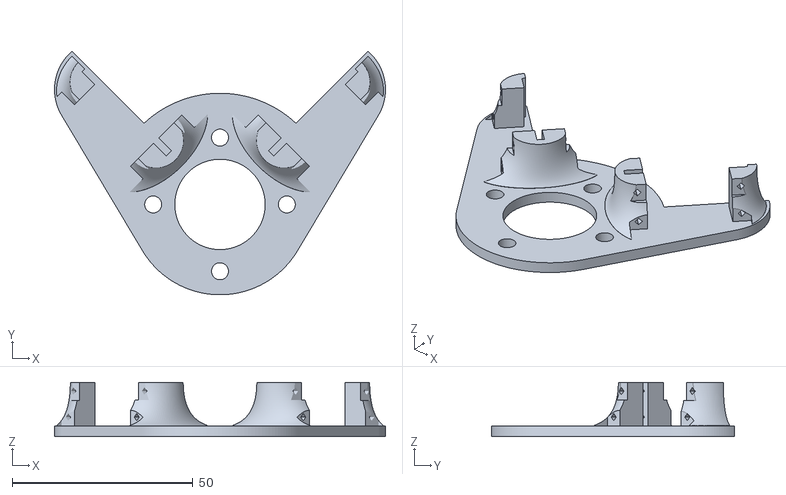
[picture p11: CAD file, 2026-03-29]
mechanical/models/3Dprint/舵机固定件.stl
91.6 x 67.4 x 15.0

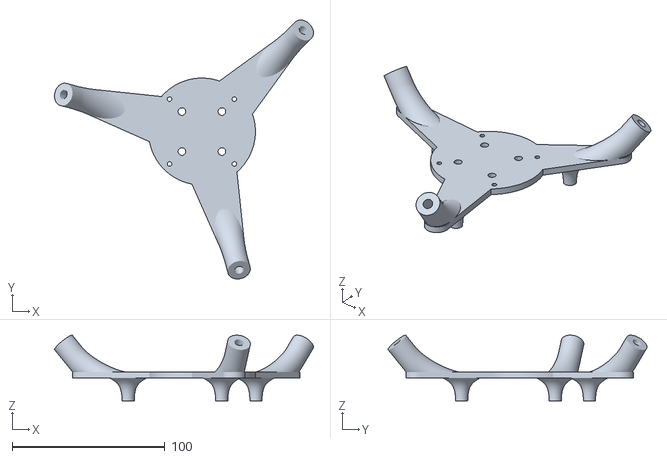
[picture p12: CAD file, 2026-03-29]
mechanical/models/3Dprint/起落架固定件_三脚.stl
169.5 x 169.5 x 43.0

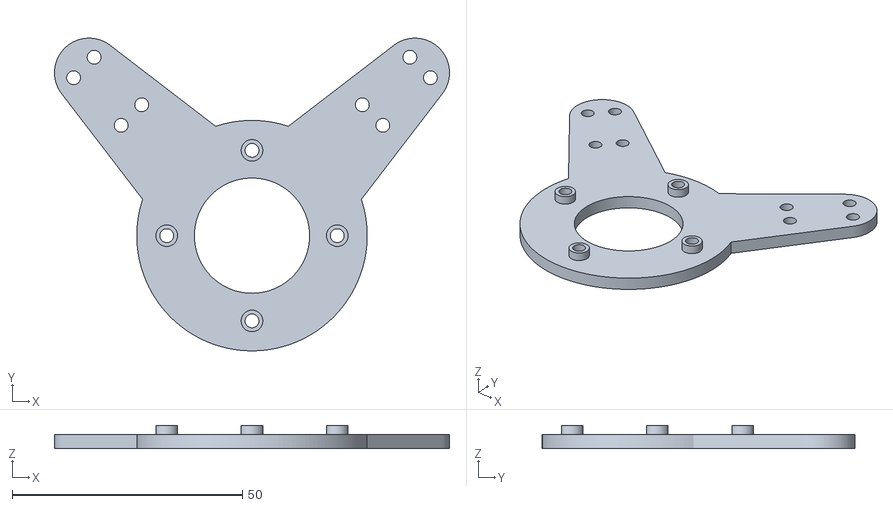
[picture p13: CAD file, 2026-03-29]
mechanical/models/3Dprint/矢量舵盘.stl
85.7 x 67.8 x 5.00

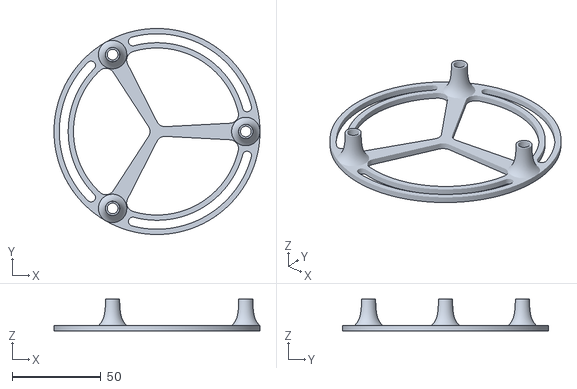
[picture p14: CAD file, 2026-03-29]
mechanical/models/3Dprint/顶盖_三脚.stl
116.0 x 116.0 x 18.0

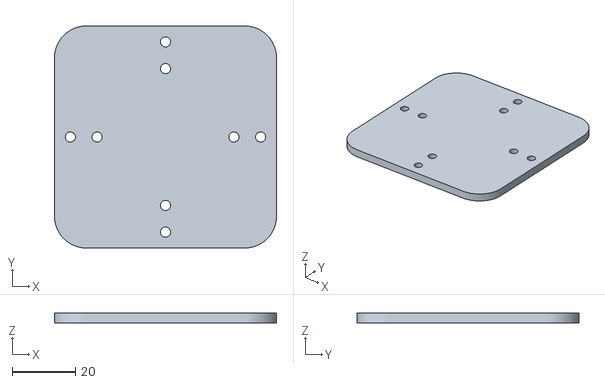
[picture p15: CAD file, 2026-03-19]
mechanical/models/3Dprint/飞控固定板.stl
70.0 x 70.0 x 3.00

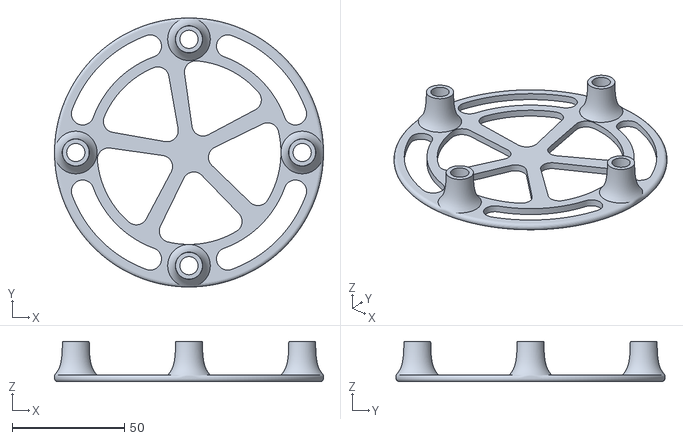
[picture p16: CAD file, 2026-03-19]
mechanical/models/3Dprint/顶盖.stl
120.0 x 120.0 x 18.0

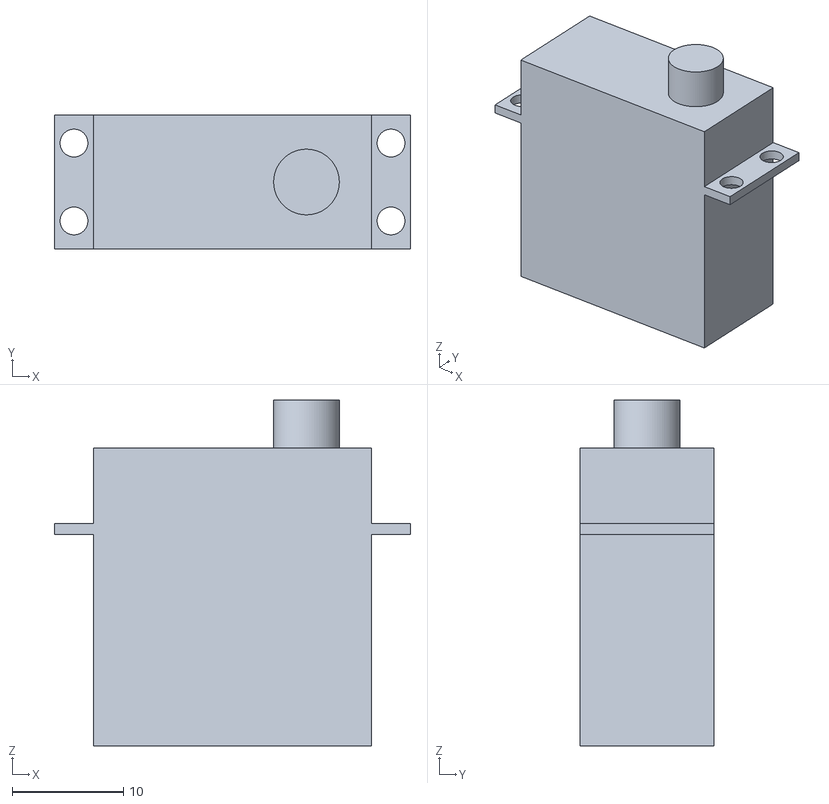
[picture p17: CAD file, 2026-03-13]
mechanical/models/3Dprint/舵机.stl
32.0 x 12.0 x 31.1

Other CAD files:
mechanical/models/3Dprint/矢量舵盘V1.gcode.3mf
mechanical/models/3Dprint/舵机固定件.gcode.3mf
mechanical/models/3Dprint/矢量舵盘.gcode.3mf
mechanical/models/3Dprint/顶盖_三脚.gcode.3mf
mechanical/models/3Dprint/飞控固定板.gcode.3mf
mechanical/models/3Dprint/顶盖.gcode.3mf
mechanical/models/3Dprint/舵机.gcode.3mf

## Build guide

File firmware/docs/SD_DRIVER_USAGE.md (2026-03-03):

# SD 卡驱动使用说明

## 概述

SD 卡驱动位于 `User/Driver/SD/`，基于 HAL_SD + FatFs，提供文件系统操作接口。  
FatFs 库位于 `3rdPartyLib/FatFs/`，由 SD 驱动引用，不直接嵌入。

## 硬件

- **接口**：SDMMC1，4-bit 模式
- **引脚**：PC8-D0, PC9-D1, PC10-D2, PC11-D3, PC12-CLK, PD2-CMD

## 初始化

`SD_Init()` 已在 `User_Main_Init()` 中调用。无卡或初始化失败时不影响系统启动，可通过 `SD_IsReady()` 检查。

## 日志写入示例

```c
#include "Driver/SD/SD.h"

void write_log_example(void)
{
    if (!SD_IsReady())
        return;

    FIL fp;
    if (SD_CreateFile("0:/log.txt", &fp) != SD_OK)
        return;

    SD_Printf(&fp, "time=%lu, roll=%.2f\r\n", (unsigned long)HAL_GetTick(), 1.23f);
    SD_Close(&fp);
}
```

## 追加写入

```c
FIL fp;
if (SD_Open("0:/log.txt", &fp, FA_OPEN_APPEND | FA_WRITE) == SD_OK) {
    SD_Write(&fp, "new line\n", 9, NULL);
    SD_Close(&fp);
}
```

## 目录操作

```c
SD_Mkdir("0:/logs");           /* 创建目录 */
SD_Unlink("0:/old.txt");       /* 删除文件 */
SD_Rename("0:/a.txt", "0:/b.txt");  /* 重命名 */
```

## 接口一览

| 函数 | 说明 |
|---|---|
| `SD_Init` / `SD_DeInit` | 初始化 / 反初始化 |
| `SD_IsReady` | 检查是否就绪 |
| `SD_CreateFile` | 创建并打开（覆盖） |
| `SD_Open` / `SD_Close` | 打开 / 关闭 |
| `SD_Write` / `SD_Read` | 写入 / 读取 |
| `SD_Printf` | 格式化写入 |
| `SD_Sync` | 刷新到磁盘 |
| `SD_Mkdir` / `SD_Unlink` / `SD_Rename` | 目录与文件管理 |
| `SD_Stat` / `SD_GetFree` | 状态与空间 |
| `SD_Opendir` / `SD_Readdir` / `SD_Closedir` | 目录遍历（参数类型 `FF_DIR`） |

路径格式：`"0:/filename.txt"`，`0:` 表示逻辑驱动器 0（SD 卡）。

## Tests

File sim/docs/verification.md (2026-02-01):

# DroneX 仿真验证标准

仿真子系统的验证指标与典型用例，用于评估动力学模型和控制算法的正确性与性能。详见 [SIMULATION_PLAN.md](SIMULATION_PLAN.md)。

---

## 1. 验证目标

- 确认动力学模型与理论一致
- 确认控制器能稳定倒立摆式无人机
- 为实机参数调试提供初值依据

---

## 2. 姿态控制验证

### 2.1 阶跃响应

| 指标 | 含义 | 目标（待定） |
| --- | --- | --- |
| 上升时间 | 达到 90% 设定值的时间 | 例：< 1.0 s |
| 超调量 | 最大 overshoot | 例：< 20% |
| 调节时间 | 进入 ±5% 误差带的时间 | 例：< 2.0 s |
| 稳态误差 | 阶跃后的稳态偏差 | 例：< 2° |

### 2.2 测试用例

- 俯仰角阶跃：0° → 10°
- 滚转角阶跃：0° → 10°
- 偏航角阶跃（若实现）：0° → 15°

---

## 3. 悬停验证

运行 `matlab/scripts/run_verify_hover.m` 可执行下述用例（切换 `scenario` 选择场景）。

### 3.1 指标

| 指标 | 含义 | 目标（待定） |
| --- | --- | --- |
| 位置误差 | 稳态水平/垂直偏差 | 例：< ±0.5 m |
| 速度误差 | 稳态速度幅值 | 例：< ±0.2 m/s |
| 姿态偏差 | 俯仰/滚转稳态角 | 例：< ±3° |

### 3.2 测试用例

- **场景 1** 定点悬停：初始位置 (0, 0, 5 m)，目标 (0, 0, 5 m)，仿真 30 s
- **场景 2** 水平平移后悬停：t < 5 s 悬停于 (0, 0, 5)，t ≥ 5 s 目标 (2, 0, 5)，观察到位与稳态

---

## 4. 抗扰验证

### 4.1 指标

| 指标 | 含义 | 目标（待定） |
| --- | --- | --- |
| 恢复时间 | 扰动后回到误差带内的时间 | 例：< 3.0 s |
| 残余误差 | 扰动撤除后的稳态偏差 | 例：< 5% 设定值 |

### 4.2 测试用例

- 阶跃风扰动：水平恒风 2 m/s 持续 5 s 后撤除
- 脉冲力矩扰动：短时施加俯仰/滚转力矩，观察恢复

---

## 5. 记录与报告

每次验证应记录：

1. 仿真参数（质量、惯量、控制增益等）
2. 典型曲线（姿态、位置、控制量）
3. 与上述指标的对比结果
4. 结论：通过/不通过，及改进建议

输出保存至 `sim/data/results/`，并汇总到仿真报告中。

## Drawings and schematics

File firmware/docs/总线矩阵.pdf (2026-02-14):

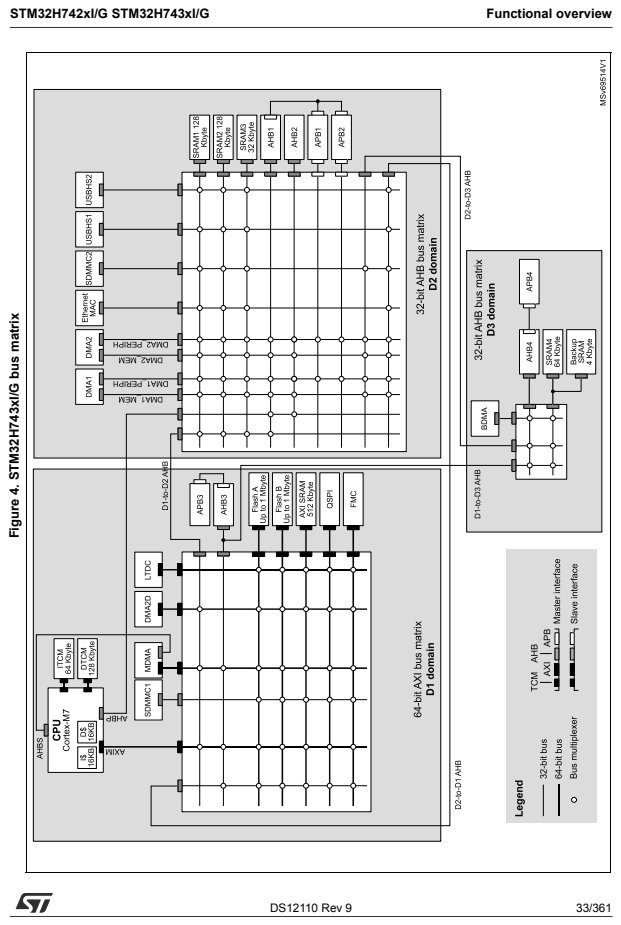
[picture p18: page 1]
STM32H742xI/G STM32H743xI/G; Functional overview; DS12110 Rev 9; 33/361 Figure 4. STM³²H⁷⁴³xI/G bus matrix

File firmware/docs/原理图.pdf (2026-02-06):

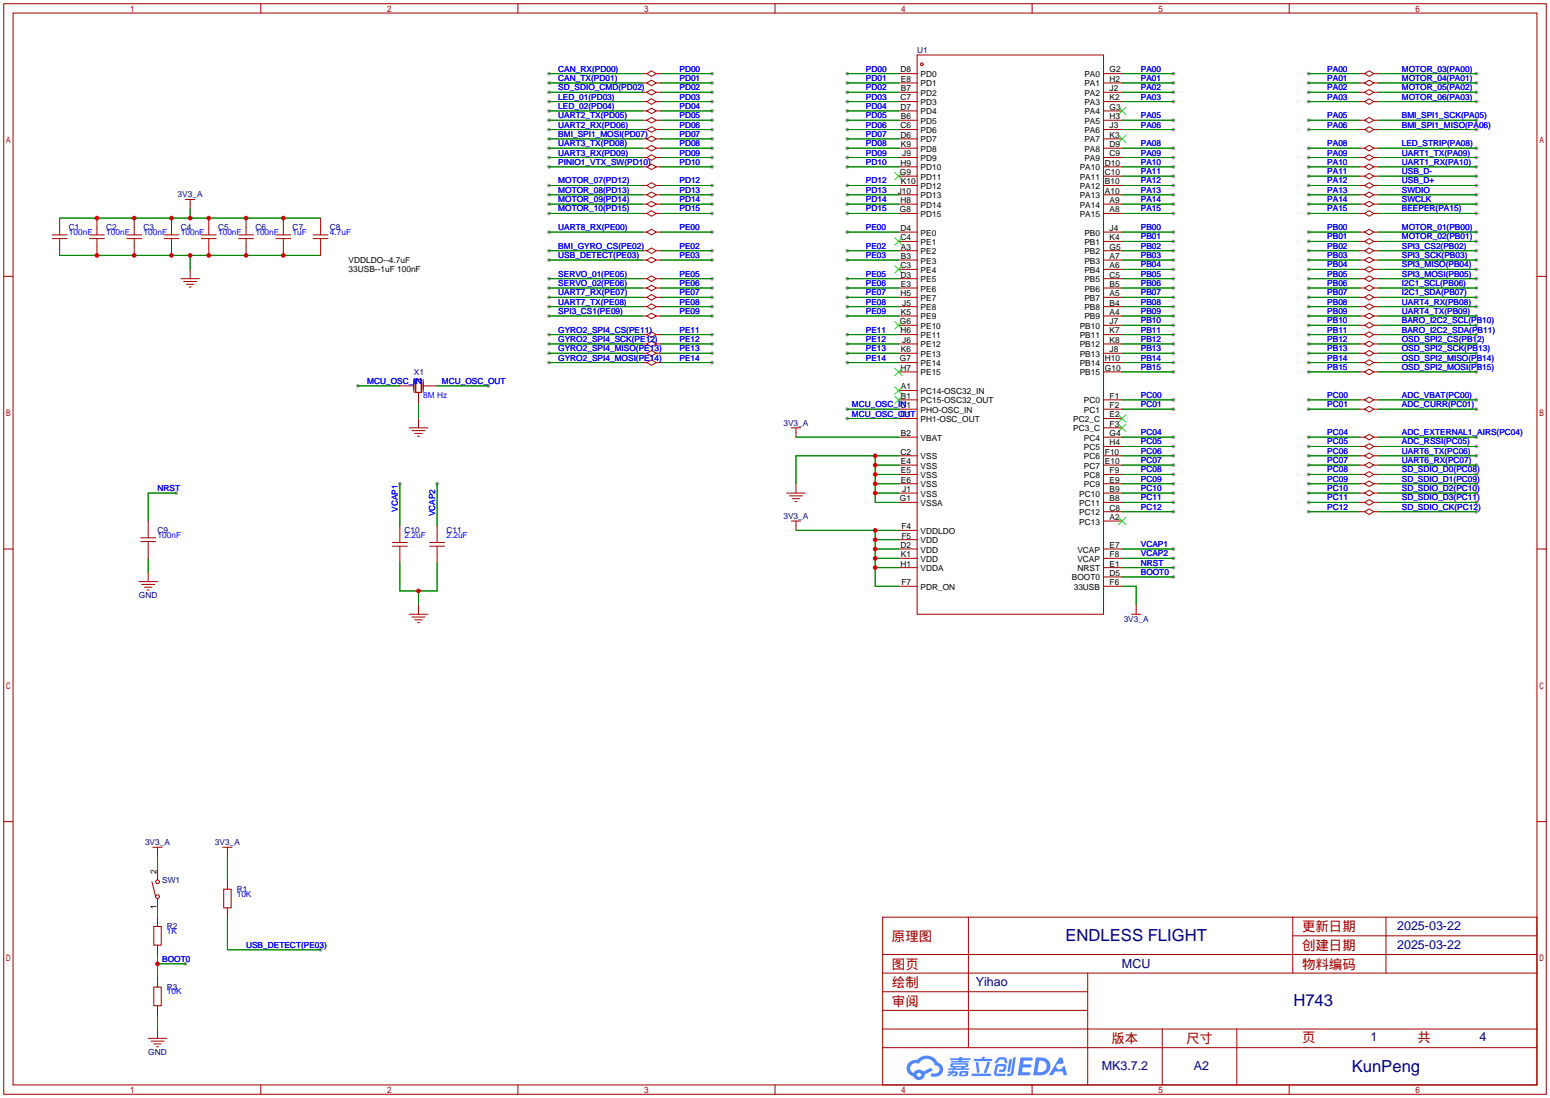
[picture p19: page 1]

# USB OTGCC¹

# LDO(5V-3.3V)

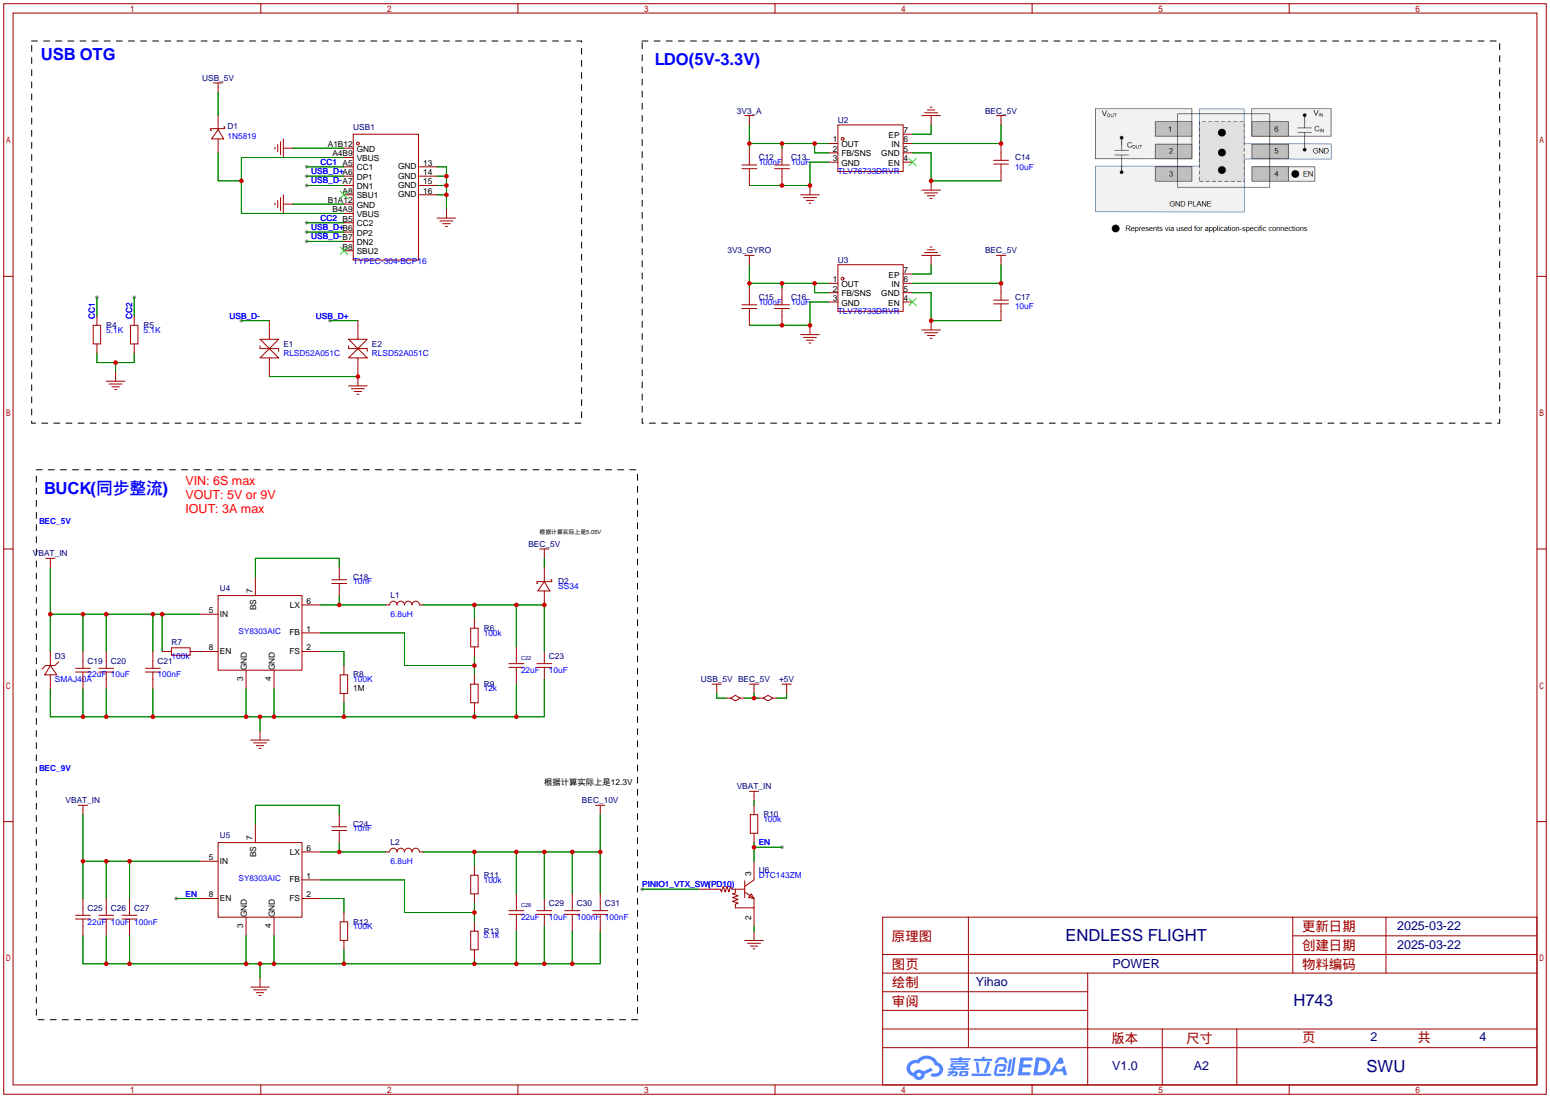
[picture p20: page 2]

GND 16 GND 15 GND 14 GND 13

图传(SPI2) | ICM42688P(SPI1)

# ICM42688P(SPI4)

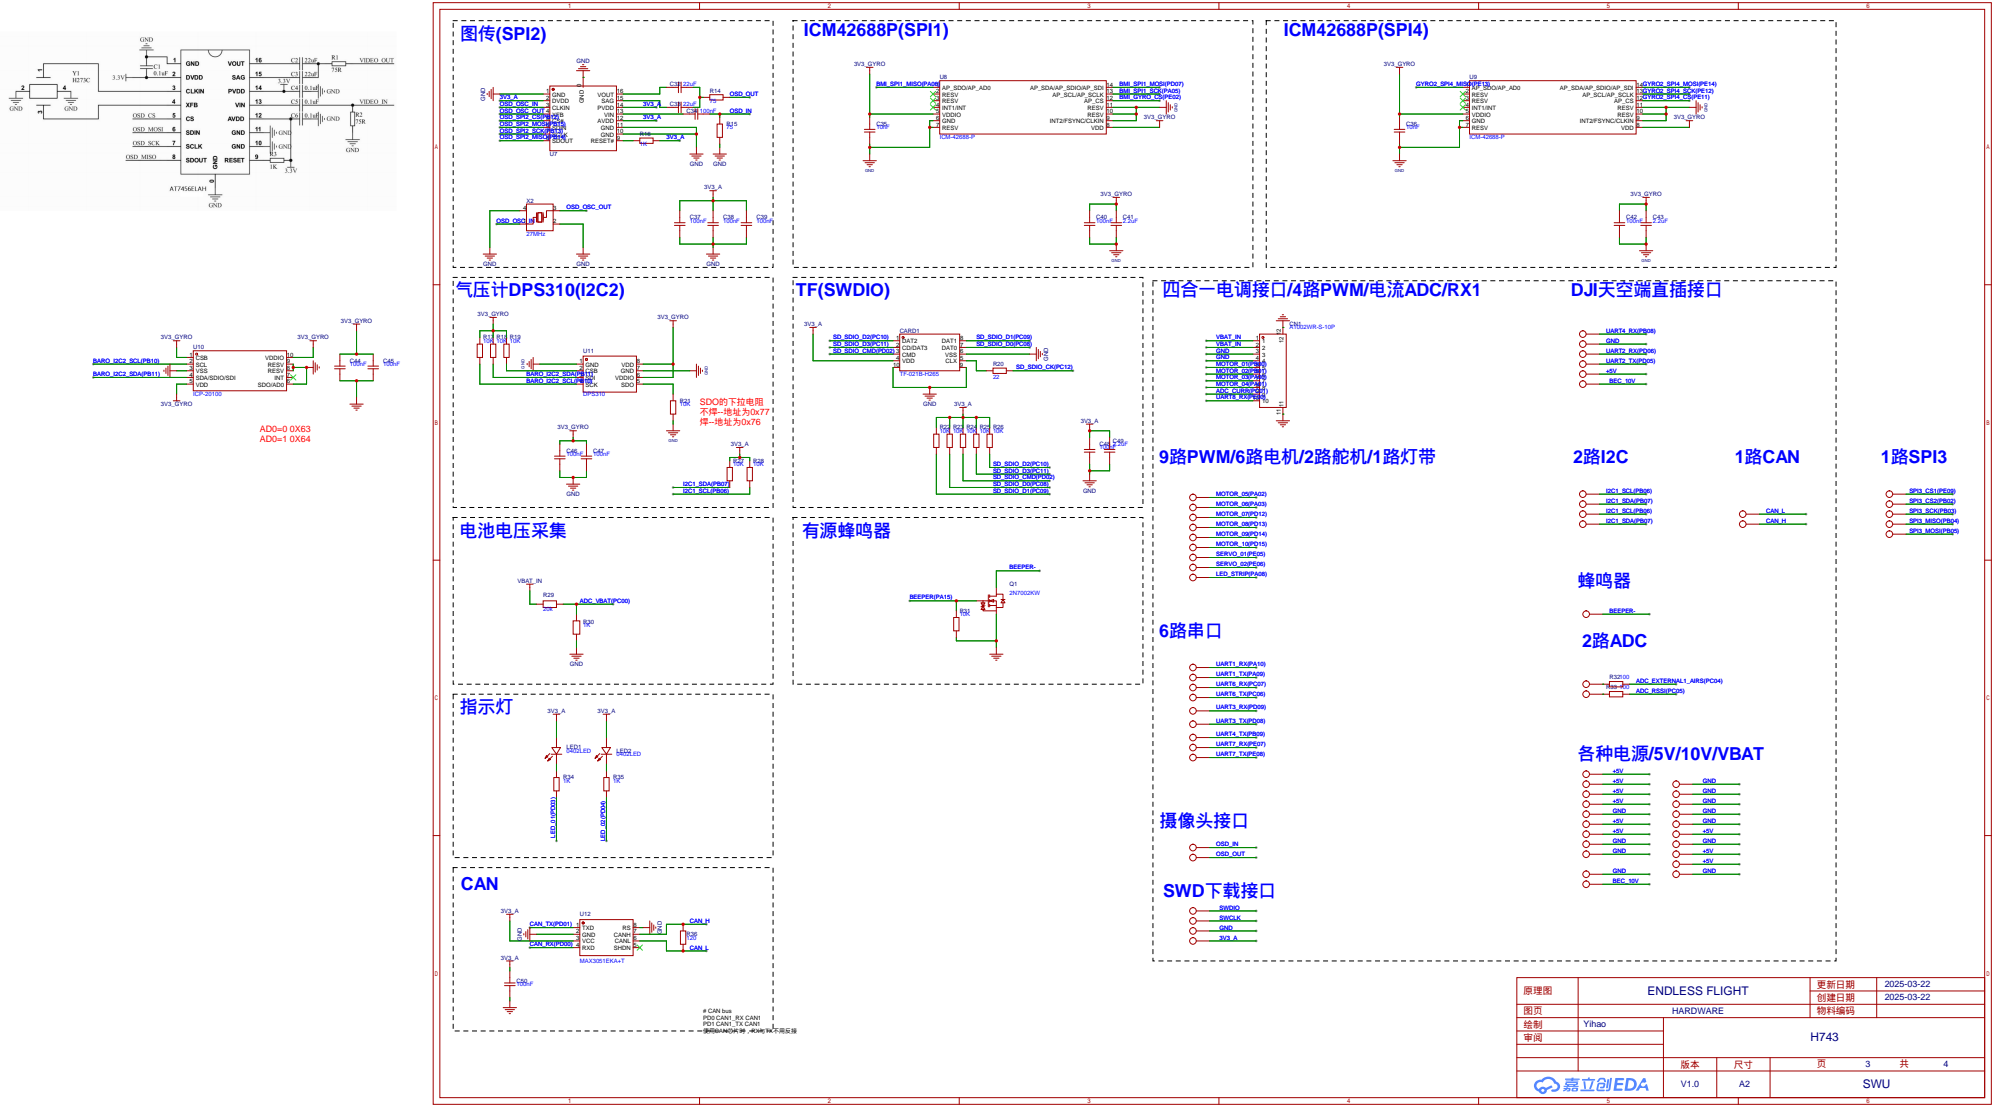
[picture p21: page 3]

GND 10 GND 11 AVDD 12 VIN 13 PVDD 14 SAG 15 VOUT 16

MK4.0 ：

# 1、优化散热，主要在板子顶层USB下方添加开窗；

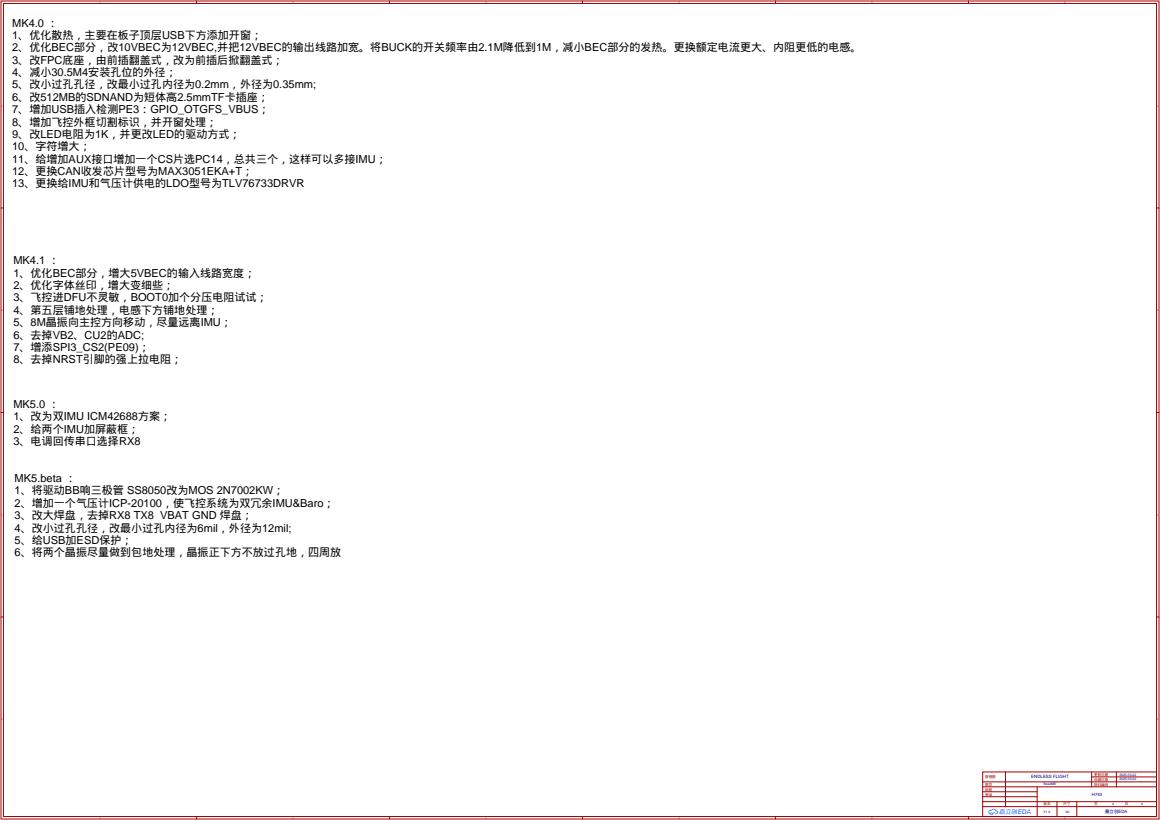
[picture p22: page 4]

MK5.beta ：
1、将驱动BB响三极管 SS8050改为MOS 2N7002KW；
2、增加一个气压计ICP-20100，使飞控系统为双冗余IMU&Baro；
3、改大焊盘，去掉RX8 TX8 VBAT GND 焊盘；
4、改小过孔孔径，改最小过孔内径为6mil，外径为12mil;
5、给USB加ESD保护；
6、将两个晶振尽量做到包地处理，晶振正下方不放过孔地，四周放

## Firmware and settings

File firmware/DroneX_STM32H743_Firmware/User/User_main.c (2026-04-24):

/**
 * @file User_main.c
 * @brief 用户主程序：初始化与主循环逻辑，由 main.c 调用。
 */

#include "User_main.h"
#include "Driver/Debug/Debug.h"
#include "Driver/Debug/Debug_UART.h"
#include "Driver/SD/SD.h"
#include "Debug/Cmd/Cmd.h"
#include "Application/Attitude/Attitude.h"
#include "Algorithm/Attitude_Est/Attitude_Est.h"
#include "Algorithm/Att_Ctrl_PID/Att_Ctrl_PID.h"
#include "Driver/IMU/IMU_interface.h"
#include "Driver/IMU/ICM42688.h"
#include "Driver/PIT/PIT.h"
#include "Driver/Timing/Timing.h"
#include "Driver/ESC/ESC.h"
#include "Driver/RC/RC.h"
#include "Driver/Vector_Gimbal/Vector_Gimbal.h"
#include "System/System_Manager.h"
#include "main.h"
#include "stm32h7xx_hal.h"
#include <string.h>

/* 陀螺仪1 句柄与配置 */
static IMU_Handle_t     s_imu1_handle;
static ICM42688_SPI_Config_t s_imu1_cfg;
/* 陀螺仪2 句柄与配置 */
static IMU_Handle_t     s_imu2_handle;
static ICM42688_SPI_Config_t s_imu2_cfg;
static float s_gimbol_cmd0 = 0;
static float s_gimbol_cmd1 = 0;
static uint32_t s_esc_print_ms = 0;
static uint32_t s_imu_last_cycles = 0U;
static uint8_t s_att_ctrl_was_run = 0U;
static uint8_t s_att_ctrl_snapshot_valid = 0U;
static float s_att_ctrl_roll_sp = 0.0f;
static float s_att_ctrl_pitch_sp = 0.0f;
static float s_att_ctrl_roll = 0.0f;
static float s_att_ctrl_pitch = 0.0f;
static float s_att_ctrl_out_x = 0.0f;
static float s_att_ctrl_out_y = 0.0f;


#define PI 3.14159265358979323846f
/* 用户主循环调试输出开关 */
#define USER_DBG_PRINT_RC_NORM       0U
#define USER_DBG_PRINT_SYS_STATE     0U
#define USER_DBG_PRINT_IMU_ATT       0U
#define USER_DBG_PRINT_IMU_BODY      0U
#define USER_DBG_PRINT_CTRL_VOFA     1U
#define USER_DBG_PRINT_PERIOD_MS    100U
#define USER_DBG_CTRL_VOFA_PERIOD_MS 20U
#define USER_ATT_CTRL_MAX_ROLL_RAD   (20.0f*PI/180.0f) /* 20 deg */
#define USER_ATT_CTRL_MAX_PITCH_RAD  (20.0f*PI/180.0f) /* 20 deg */

static const Att_Ctrl_PID_Config_t s_att_ctrl_cfg = {
    .gains_roll_angle = { 8.0f, 0.0f, 0.0f },
    .gains_pitch_angle = { 8.0f, 0.0f, 0.0f },
    .gains_roll_rate = { 0.12f, 0.0f, 0.002f },
    .gains_pitch_rate = { 0.12f, 0.0f, 0.002f },

    .roll_angle_out_min = -4.0f,
    .roll_angle_out_max = 4.0f,
    .pitch_angle_out_min = -4.0f,
    .pitch_angle_out_max = 4.0f,

    .enable_roll_angle_i_limit = 0U,
    .roll_angle_i_min = 0.0f,
    .roll_angle_i_max = 0.0f,
    .enable_pitch_angle_i_limit = 0U,
    .pitch_angle_i_min = 0.0f,
    .pitch_angle_i_max = 0.0f,

    .roll_rate_out_min = -1.0f,
    .roll_rate_out_max = 1.0f,
    .pitch_rate_out_min = -1.0f,
    .pitch_rate_out_max = 1.0f,

    .enable_roll_rate_i_limit = 0U,
    .roll_rate_i_min = 0.0f,
    .roll_rate_i_max = 0.0f,
    .enable_pitch_rate_i_limit = 0U,
    .pitch_rate_i_min = 0.0f,
    .pitch_rate_i_max = 0.0f,

    .gyro_lpf_tau_s = 0.02f,

    .servo_min_norm = -1.0f,
    .servo_max_norm = 1.0f,

    .roll_servo_gain = 1.0f,
    .pitch_servo_gain = 1.0f,
    .servo_trim_norm = { 0.0f, 0.0f },
};

/* 动力转发任务：由 System 层根据状态决定是否/如何下发动力命令。 */
static void System_Power_Task(void)
{
    System_Manager_PowerControlTask();
}

static float Rc_ToNorm(int16_t rc_norm)
{
    float v = (float)rc_norm * 0.001f;

    if (v < -1.0f) {
        return -1.0f;
    }
    if (v > 1.0f) {
        return 1.0f;
    }
    return v;
}

static uint32_t User_GetMonotonicUs(void)
{
    static uint8_t inited = 0U;
    static uint32_t last_cycles = 0U;
    static uint32_t time_us = 0U;
    uint32_t now_cycles = Timing_GetCycles();

    if (inited == 0U) {
        last_cycles = now_cycles;
        inited = 1U;
        return time_us;
    }

    time_us += Timing_CyclesToUs(now_cycles - last_cycles);
    last_cycles = now_cycles;
    return time_us;
}

static void Vector_Gimbal_ManualTask(const RC_Signal_t *rc)
{
    if (rc == NULL) {
        return;
    }

    s_gimbol_cmd0 = Rc_ToNorm(rc->ch[0]);
    s_gimbol_cmd1 = Rc_ToNorm(rc->ch[1]);
    (void)Vector_Gimbal_SetNormalized(VECTOR_GIMBAL_AXIS_X, s_gimbol_cmd0);
    (void)Vector_Gimbal_SetNormalized(VECTOR_GIMBAL_AXIS_Y, s_gimbol_cmd1);
}

static void Vector_Gimbal_AutoTask(const RC_Signal_t *rc)
{
    float roll;
    float pitch;
    float omega[3];
    float out_x;
    float out_y;
    Att_Ctrl_PID_In_t in;
    Att_Ctrl_PID_Out_t out;
    int rc_pid;

    if ((rc == NULL) || (rc->is_online == 0U) || !Attitude_Est_IsReady()) {
        (void)Vector_Gimbal_SetNormalized(VECTOR_GIMBAL_AXIS_X, 0.0f);
        (void)Vector_Gimbal_SetNormalized(VECTOR_GIMBAL_AXIS_Y, 0.0f);
        s_att_ctrl_snapshot_valid = 0U;
        Att_Ctrl_PID_Reset();
        return;
    }

    Attitude_Est_GetEuler(&roll, &pitch, NULL);
    Attitude_Est_GetAngularRate(omega);

    memset(&in, 0, sizeof(in));
    in.roll_rad = roll;
    in.pitch_rad = pitch;
    /* Attitude_Est defines roll about body Y, pitch about body X. */
    in.roll_rate_fb_rad_s = omega[1];
    in.pitch_rate_fb_rad_s = omega[0];
    in.roll_sp_rad = Rc_ToNorm(rc->ch[0]) * USER_ATT_CTRL_MAX_ROLL_RAD;
    in.pitch_sp_rad = -Rc_ToNorm(rc->ch[1]) * USER_ATT_CTRL_MAX_PITCH_RAD;
    in.time_us = User_GetMonotonicUs();

    rc_pid = Att_Ctrl_PID_Update(&in, &out);
    if (rc_pid == ATT_CTRL_PID_ERR_TIME) {
        Att_Ctrl_PID_Reset();
        rc_pid = Att_Ctrl_PID_Update(&in, &out);
    }
    if (rc_pid == ATT_CTRL_PID_OK) {
        out_x = out.servo_norm[0];
        out_y = -out.servo_norm[1];
        (void)Vector_Gimbal_SetNormalized(VECTOR_GIMBAL_AXIS_X, out_x);
        (void)Vector_Gimbal_SetNormalized(VECTOR_GIMBAL_AXIS_Y, out_y);

        s_att_ctrl_roll_sp = in.roll_sp_rad;
        s_att_ctrl_pitch_sp = in.pitch_sp_rad;
        s_att_ctrl_roll = roll;
        s_att_ctrl_pitch = pitch;
        s_att_ctrl_out_x = out_x;
        s_att_ctrl_out_y = out_y;
        s_att_ctrl_snapshot_valid = 1U;
    } else {
        s_att_ctrl_snapshot_valid = 0U;
    }
}

/** Debug 层：Driver 拆包后的指令包回调，交由 Cmd 解析执行 */
static void Debug_CtrlVofaTask(uint32_t now_ms)
{
    static uint32_t s_last_vofa_ms = 0U;

    if (USER_DBG_PRINT_CTRL_VOFA == 0U) {
        return;
    }
    if ((now_ms - s_last_vofa_ms) < USER_DBG_CTRL_VOFA_PERIOD_MS) {
        return;
    }
    if ((s_att_ctrl_snapshot_valid == 0U) || (Debug_IsQueueEmpty() == 0)) {
        return;
    }

    s_last_vofa_ms = now_ms;
    (void)Debug_Printf("%.6f,%.6f,%.6f\n",
                       (double)s_att_ctrl_pitch_sp,
                       (double)s_att_ctrl_pitch,
                       (double)s_att_ctrl_out_y);
}

static void Debug_OnLine(const char *buf)
{
    Cmd_Status_t ret = Cmd_Process(buf);
    if (ret == CMD_ERR_UNKNOWN)
        Debug_Printf("ERR unknown cmd:[%s]\r\n", buf);
    else if (ret == CMD_ERR_PARAM || ret == CMD_ERR_TOO_LONG)
        Debug_Printf("ERR format\r\n");
}

/** 200Hz 定时任务：读取双 IMU，解算姿态，输出欧拉角与周期耗时 [roll pitch yaw] deg, [us] */
static void IMU_500Hz_Task(void)
{
    uint32_t now_cycles = Timing_GetCycles();
    float dt_s = 0.005f;

    if (s_imu_last_cycles != 0U) {
        uint32_t dt_us = Timing_CyclesToUs(now_cycles - s_imu_last_cycles);
        if ((dt_us >= 1000U) && (dt_us <= 20000U)) {
            dt_s = (float)dt_us * 1.0e-6f;
        }
    }
    s_imu_last_cycles = now_cycles;

    IMU_Data_t data1, data2;
    int ok1 = (IMU_Read(&s_imu1_handle, &data1) == IMU_OK);
    int ok2 = (IMU_Read(&s_imu2_handle, &data2) == IMU_OK);

    Attitude_OnImuSample(ok1 ? &data1 : NULL, ok1, ok2 ? &data2 : NULL, ok2);

    if (ok1 && ok2)
        Attitude_Est_Update(&data1, &data2, dt_s);
    else if (ok1)
        Attitude_Est_Update(&data1, NULL, dt_s);
    else if (ok2)
        Attitude_Est_Update(NULL, &data2, dt_s);

    if (Attitude_Est_IsReady()) {
        float roll, pitch, yaw;
        Attitude_Est_GetEuler(&roll, &pitch, &yaw);
        // Debug_Printf("EUL %.2f %.2f %.2f dt=%.4f\r\n",
        //     (double)(roll * 57.29577951308232f),
        //     (double)(pitch * 57.29577951308232f),
        //     (double)(yaw * 57.29577951308232f),
        //     (double)dt_s);
    }
}

/**
 * @brief 用户初始化
 */
void User_Main_Init(void)
{
    Debug_Init(Debug_Transport_Send);
    Cmd_Init();
    Cmd_RegisterBuiltins();
    Debug_UART_SetLineCallback(Debug_OnLine);
    Debug_UART_Init();
    RC_Init();

    Timing_Init();
    Attitude_Est_Init();
    Attitude_Init();
    (void)Att_Ctrl_PID_Init(&s_att_ctrl_cfg);

    /* 陀螺仪1：SPI1，CS=PE2 */
    s_imu1_cfg.hspi   = &hspi1;
    s_imu1_cfg.cs_port = GPIOE;
    s_imu1_cfg.cs_pin  = GPIO_PIN_2;
    IMU_Interface_Init(&s_imu1_handle, IMU_TYPE_ICM42688, &s_imu1_cfg);

    (void)IMU_Init(&s_imu1_handle);

    /* 陀螺仪2：SPI4，CS=PE11 */
    s_imu2_cfg.hspi    = &hspi4;
    s_imu2_cfg.cs_port = GPIOE;
    s_imu2_cfg.cs_pin  = GPIO_PIN_11;
    IMU_Interface_Init(&s_imu2_handle, IMU_TYPE_ICM42688, &s_imu2_cfg);

    (void)IMU_Init(&s_imu2_handle);

    /* SD 卡初始化（可选：无卡时不影响启动，日志模块可调用 SD_IsReady 检查） */
    // (void)SD_Init();

    /* ESC 初始化：双向 DShot300（TIM2_CH3/CH4），上电先发送停转帧 */
    if (ESC_Init() == ESC_OK) {
        Debug_BlockingPrintf("ESC_Init OK\r\n");
        ESC_Service_Init();
        // (void)ESC_SetThrottleBidirectional(ESC_CH1, 0);
        // (void)ESC_SetThrottleBidirectional(ESC_CH2, 0);
        // (void)ESC_Update();
        HAL_Delay(1000);
    }
    else {
        Debug_BlockingPrintf("ESC_Init FAILED\r\n");
    }
    

    /* 云台舵机：TIM4_CH3/CH4 -> PD14/PD15，约333Hz，接口 -10000..10000 */
    Vector_Gimbal_Init();

    /* 200Hz IMU 任务：PIT_CH0，周期 5000us，NVIC 优先级 1（高优先级） */
    PIT_Config_t pit_cfg = {
        .period_us = 5000,   /* 200Hz = 5ms */
        .priority  = 1,
        .callback  = IMU_500Hz_Task,
    };
    if (PIT_Init(PIT_CH0, &pit_cfg) == PIT_OK)
        PIT_Start(PIT_CH0);

    /* 200Hz 姿态解算任务：PIT_CH1（含 imu_cali 占位实现） */
    pit_cfg.period_us = 5000;
    pit_cfg.priority  = 2;
    pit_cfg.callback  = Attitude_Task;
    if (PIT_Init(PIT_CH1, &pit_cfg) == PIT_OK)
        // PIT_Start(PIT_CH1);

    /* DShot300 发送节拍：250us ≈ 4kHz（与常见飞控一致，高于原 500Hz） */
    pit_cfg.period_us = 250;
    pit_cfg.priority  = 3;
    pit_cfg.callback  = System_Power_Task;
    if (PIT_Init(PIT_CH2, &pit_cfg) == PIT_OK)
        PIT_Start(PIT_CH2);

    System_Manager_Init();
}

/**
 * @brief 用户主循环体
 */
void User_Main_Loop(void)
{
    const RC_Signal_t *rc = RC_GetSignal();
    uint32_t now = HAL_GetTick();
    if ((now - s_esc_print_ms) >= USER_DBG_PRINT_PERIOD_MS) {
        s_esc_print_ms = now;
        if (USER_DBG_PRINT_RC_NORM != 0U) {
            /* 输出遥控器归一化通道（-1000..1000）和关键状态位 */
            Debug_Printf(
                "RC norm ch1=%d ch2=%d ch3=%d ch4=%d ch5=%d ch6=%d ch7=%d ch8=%d ch9=%d ch10=%d ch11=%d ch12=%d ch13=%d ch14=%d ch15=%d ch16=%d sw17=%u sw18=%u online=%u lost=%u fs=%u\r\n",
                (int)rc->ch[0],
                (int)rc->ch[1],
                (int)rc->ch[2],
                (int)rc->ch[3],
                (int)rc->ch[4],
                (int)rc->ch[5],
                (int)rc->ch[6],
                (int)rc->ch[7],
                (int)rc->ch[8],
                (int)rc->ch[9],
                (int)rc->ch[10],
                (int)rc->ch[11],
                (int)rc->ch[12],
                (int)rc->ch[13],
                (int)rc->ch[14],
                (int)rc->ch[15],
                (unsigned)rc->ch17,
                (unsigned)rc->ch18,
                (unsigned)rc->is_online,
                (unsigned)rc->frame_lost,
                (unsigned)rc->failsafe);
        }
        if (USER_DBG_PRINT_SYS_STATE != 0U) {
            const System_State_t *sys = System_Manager_GetState();
            Debug_Printf(
                "SYS mode=%d fault=0x%08lx armed=%u pwr_act=%u pwr_out=%u reboot=%u safety=%u\r\n",
                (int)sys->mode,
                (unsigned long)sys->fault_flags,
                (unsigned)sys->armed,
                (unsigned)sys->power_unit_activated,
                (unsigned)sys->power_output_enabled,
                (unsigned)sys->reboot_required,
                (unsigned)sys->safety_triggered);
        }
        if (USER_DBG_PRINT_IMU_ATT != 0U) {
            if (Attitude_Est_IsReady()) {
                float roll, pitch, yaw;
                Attitude_Est_GetEuler(&roll, &pitch, &yaw);

                Debug_Printf(
                    "ATT deg roll=%.2f pitch=%.2f yaw=%.2f\r\n",
                    (double)(roll * 57.29577951308232f),
                    (double)(pitch * 57.29577951308232f),
                    (double)(yaw * 57.29577951308232f));
            } else {
                Debug_Printf("ATT not-ready\r\n");
            }
        }
        if (USER_DBG_PRINT_IMU_BODY != 0U) {
            IMU_Data_t imu1_body;
            IMU_Data_t imu2_body;
            int imu1_ready;
            int imu2_ready;

            __disable_irq();
            imu1_ready = (Attitude_Est_GetImuBodyData(ATTITUDE_EST_IMU_1, &imu1_body) == ATTITUDE_EST_OK);
            imu2_ready = (Attitude_Est_GetImuBodyData(ATTITUDE_EST_IMU_2, &imu2_body) == ATTITUDE_EST_OK);
            __enable_irq();

            if (imu1_ready != 0) {
                Debug_Printf("IMU1 body gyro=[%.5f %.5f %.5f] acc=[%.5f %.5f %.5f]\r\n",
                            (double)imu1_body.gyro[0],
                            (double)imu1_body.gyro[1],
                            (double)imu1_body.gyro[2],
                            (double)imu1_body.accel[0],
                            (double)imu1_body.accel[1],
                            (double)imu1_body.accel[2]);
            } else {
                Debug_Printf("IMU1 body not-ready\r\n");
            }

            if (imu2_ready != 0) {
                Debug_Printf("IMU2 body gyro=[%.5f %.5f %.5f] acc=[%.5f %.5f %.5f]\r\n",
                            (double)imu2_body.gyro[0],
                            (double)imu2_body.gyro[1],
                            (double)imu2_body.gyro[2],
                            (double)imu2_body.accel[0],
                            (double)imu2_body.accel[1],
                            (double)imu2_body.accel[2]);
            } else {
                Debug_Printf("IMU2 body not-ready\r\n");
            }
        }
    }

    if (System_Manager_GetState()->mode == SYS_MODE_RUN) {
        if (s_att_ctrl_was_run == 0U) {
            Att_Ctrl_PID_Reset();
            s_att_ctrl_was_run = 1U;
        }
        Vector_Gimbal_AutoTask(rc);
    } else {
        if (s_att_ctrl_was_run != 0U) {
            Att_Ctrl_PID_Reset();
            s_att_ctrl_was_run = 0U;
        }
        s_att_ctrl_snapshot_valid = 0U;
        Vector_Gimbal_ManualTask(rc);
    }

    Debug_CtrlVofaTask(HAL_GetTick());

    Debug_UART_Process();
    RC_Process();
    System_Manager_Tick1ms();
    Debug_Process();
}

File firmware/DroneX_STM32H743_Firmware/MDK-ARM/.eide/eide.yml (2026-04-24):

version: "4.1"
name: DroneX_STM32H743_Firmware
type: ARM
deviceName: null
packDir: null
srcDirs:
  - ../User
  - ../3rdPartyLib
virtualFolder:
  name: <virtual_root>
  files: []
  folders:
    - name: Application
      files: []
      folders:
        - name: MDK-ARM
          files:
            - path: startup_stm32h743xx.s
          folders: []
        - name: User
          files: []
          folders:
            - name: Core
              files:
                - path: ../Core/Src/main.c
                - path: ../Core/Src/stm32h7xx_it.c
                - path: ../Core/Src/stm32h7xx_hal_msp.c
              folders: []
    - name: Drivers
      files: []
      folders:
        - name: STM32H7xx_HAL_Driver
          files:
            - path: ../Drivers/STM32H7xx_HAL_Driver/Src/stm32h7xx_hal_cortex.c
            - path: ../Drivers/STM32H7xx_HAL_Driver/Src/stm32h7xx_hal_rcc.c
            - path: ../Drivers/STM32H7xx_HAL_Driver/Src/stm32h7xx_hal_rcc_ex.c
            - path: ../Drivers/STM32H7xx_HAL_Driver/Src/stm32h7xx_hal_flash.c
            - path: ../Drivers/STM32H7xx_HAL_Driver/Src/stm32h7xx_hal_flash_ex.c
            - path: ../Drivers/STM32H7xx_HAL_Driver/Src/stm32h7xx_hal_gpio.c
            - path: ../Drivers/STM32H7xx_HAL_Driver/Src/stm32h7xx_hal_hsem.c
            - path: ../Drivers/STM32H7xx_HAL_Driver/Src/stm32h7xx_hal_dma.c
            - path: ../Drivers/STM32H7xx_HAL_Driver/Src/stm32h7xx_hal_dma_ex.c
            - path: ../Drivers/STM32H7xx_HAL_Driver/Src/stm32h7xx_hal_mdma.c
            - path: ../Drivers/STM32H7xx_HAL_Driver/Src/stm32h7xx_hal_pwr.c
            - path: ../Drivers/STM32H7xx_HAL_Driver/Src/stm32h7xx_hal_pwr_ex.c
            - path: ../Drivers/STM32H7xx_HAL_Driver/Src/stm32h7xx_hal.c
            - path: ../Drivers/STM32H7xx_HAL_Driver/Src/stm32h7xx_hal_i2c.c
            - path: ../Drivers/STM32H7xx_HAL_Driver/Src/stm32h7xx_hal_i2c_ex.c
            - path: ../Drivers/STM32H7xx_HAL_Driver/Src/stm32h7xx_hal_exti.c
            - path: ../Drivers/STM32H7xx_HAL_Driver/Src/stm32h7xx_hal_tim.c
            - path: ../Drivers/STM32H7xx_HAL_Driver/Src/stm32h7xx_hal_tim_ex.c
            - path: ../Drivers/STM32H7xx_HAL_Driver/Src/stm32h7xx_hal_adc.c
            - path: ../Drivers/STM32H7xx_HAL_Driver/Src/stm32h7xx_hal_adc_ex.c
            - path: ../Drivers/STM32H7xx_HAL_Driver/Src/stm32h7xx_hal_cec.c
            - path: ../Drivers/STM32H7xx_HAL_Driver/Src/stm32h7xx_hal_comp.c
            - path: ../Drivers/STM32H7xx_HAL_Driver/Src/stm32h7xx_hal_cordic.c
            - path: ../Drivers/STM32H7xx_HAL_Driver/Src/stm32h7xx_hal_crc.c
            - path: ../Drivers/STM32H7xx_HAL_Driver/Src/stm32h7xx_hal_crc_ex.c
            - path: ../Drivers/STM32H7xx_HAL_Driver/Src/stm32h7xx_hal_cryp.c
            - path: ../Drivers/STM32H7xx_HAL_Driver/Src/stm32h7xx_hal_cryp_ex.c
            - path: ../Drivers/STM32H7xx_HAL_Driver/Src/stm32h7xx_hal_dac.c
            - path: ../Drivers/STM32H7xx_HAL_Driver/Src/stm32h7xx_hal_dac_ex.c
            - path: ../Drivers/STM32H7xx_HAL_Driver/Src/stm32h7xx_hal_dcmi.c
            - path: ../Drivers/STM32H7xx_HAL_Driver/Src/stm32h7xx_hal_dfsdm.c
            - path: ../Drivers/STM32H7xx_HAL_Driver/Src/stm32h7xx_hal_dfsdm_ex.c
            - path: ../Drivers/STM32H7xx_HAL_Driver/Src/stm32h7xx_hal_dma2d.c
            - path: ../Drivers/STM32H7xx_HAL_Driver/Src/stm32h7xx_hal_dsi.c
            - path: ../Drivers/STM32H7xx_HAL_Driver/Src/stm32h7xx_hal_dts.c
            - path: ../Drivers/STM32H7xx_HAL_Driver/Src/stm32h7xx_hal_eth.c
            - path: ../Drivers/STM32H7xx_HAL_Driver/Src/stm32h7xx_hal_eth_ex.c
            - path: ../Drivers/STM32H7xx_HAL_Driver/Src/stm32h7xx_hal_fdcan.c
            - path: ../Drivers/STM32H7xx_HAL_Driver/Src/stm32h7xx_hal_fmac.c
            - path: ../Drivers/STM32H7xx_HAL_Driver/Src/stm32h7xx_hal_gfxmmu.c
            - path: ../Drivers/STM32H7xx_HAL_Driver/Src/stm32h7xx_hal_hash.c
            - path: ../Drivers/STM32H7xx_HAL_Driver/Src/stm32h7xx_hal_hash_ex.c
            - path: ../Drivers/STM32H7xx_HAL_Driver/Src/stm32h7xx_hal_hcd.c
            - path: ../Drivers/STM32H7xx_HAL_Driver/Src/stm32h7xx_hal_hrtim.c
            - path: ../Drivers/STM32H7xx_HAL_Driver/Src/stm32h7xx_hal_i2s.c
            - path: ../Drivers/STM32H7xx_HAL_Driver/Src/stm32h7xx_hal_i2s_ex.c
            - path: ../Drivers/STM32H7xx_HAL_Driver/Src/stm32h7xx_hal_irda.c
            - path: ../Drivers/STM32H7xx_HAL_Driver/Src/stm32h7xx_hal_iwdg.c
            - path: ../Drivers/STM32H7xx_HAL_Driver/Src/stm32h7xx_hal_jpeg.c
            - path: ../Drivers/STM32H7xx_HAL_Driver/Src/stm32h7xx_hal_lptim.c
            - path: ../Drivers/STM32H7xx_HAL_Driver/Src/stm32h7xx_hal_ltdc.c
            - path: ../Drivers/STM32H7xx_HAL_Driver/Src/stm32h7xx_hal_ltdc_ex.c
            - path: ../Drivers/STM32H7xx_HAL_Driver/Src/stm32h7xx_hal_mdios.c
            - path: ../Drivers/STM32H7xx_HAL_Driver/Src/stm32h7xx_hal_mmc.c
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

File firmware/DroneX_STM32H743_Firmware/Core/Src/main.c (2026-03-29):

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
/* Includes ------------------------------------------------------------------*/
#include "main.h"

/* USER CODE BEGIN Includes */
#include "User_main.h"
#include "Driver/Debug/Debug.h"
/* USER CODE END Includes */


/* USER CODE BEGIN PV */
UART_HandleTypeDef huart1;
UART_HandleTypeDef huart6;
DMA_HandleTypeDef hdma_usart1_tx;
SPI_HandleTypeDef hspi1;
SPI_HandleTypeDef hspi4;
static uint32_t s_reset_flags_snapshot = 0U;
/* USER CODE END PV */

void SystemClock_Config(void);
static void MPU_Config(void);
static void MX_GPIO_Init(void);
/**
  * @brief  The application entry point.
  * @retval int
  */
int main(void)
{

  /* USER CODE BEGIN 1 */
  s_reset_flags_snapshot = RCC->RSR;
  __HAL_RCC_CLEAR_RESET_FLAGS();

  /* USER CODE END 1 */

  /* MPU Configuration--------------------------------------------------------*/
  MPU_Config();

  /* MCU Configuration--------------------------------------------------------*/

  /* Reset of all peripherals, Initializes the Flash interface and the Systick. */
  HAL_Init();

  /* Configure the system clock */
  SystemClock_Config();

  /* Initialize all configured peripherals */
  MX_GPIO_Init();
  MX_USART1_UART_Init();
  MX_USART6_UART_Init();
  MX_SPI1_Init();
  MX_SPI4_Init();
  /* USER CODE BEGIN 2 */
  User_Main_Init();
  Debug_BlockingPrintf("[BOOT] reset_flags=0x%08lx (PIN=%u POR=%u SFT=%u IWDG=%u WWDG=%u LPWR=%u)\r\n",
                       (unsigned long)s_reset_flags_snapshot,
                       (unsigned)((s_reset_flags_snapshot & RCC_RSR_PINRSTF)  ? 1U : 0U),
                       (unsigned)((s_reset_flags_snapshot & RCC_RSR_PORRSTF)  ? 1U : 0U),
                       (unsigned)((s_reset_flags_snapshot & RCC_RSR_SFTRSTF)  ? 1U : 0U),
                       (unsigned)((s_reset_flags_snapshot & RCC_RSR_IWDG1RSTF)? 1U : 0U),
                       (unsigned)((s_reset_flags_snapshot & RCC_RSR_WWDG1RSTF)? 1U : 0U),
                       (unsigned)((s_reset_flags_snapshot & RCC_RSR_LPWRRSTF) ? 1U : 0U));
  /* USER CODE END 2 */

  /* Infinite loop */
  /* USER CODE BEGIN WHILE */
  while (1)
  {
    /* USER CODE END WHILE */
    User_Main_Loop();
    /* USER CODE BEGIN 3 */
  }
  /* USER CODE END 3 */
}

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
/* USER CODE BEGIN 4 */

/**
  * @brief USART1 初始化：PA9(TX) PA10(RX)，115200 8N1，DMA TX
  */
void MX_USART1_UART_Init(void)
{
  huart1.Instance = USART1;
  huart1.Init.BaudRate = 2000000;
  huart1.Init.WordLength = UART_WORDLENGTH_8B;
  huart1.Init.StopBits = UART_STOPBITS_1;
  huart1.Init.Parity = UART_PARITY_NONE;
  huart1.Init.Mode = UART_MODE_TX_RX;
  huart1.Init.HwFlowCtl = UART_HWCONTROL_NONE;
  huart1.Init.OverSampling = UART_OVERSAMPLING_16;
  huart1.Init.OneBitSampling = UART_ONE_BIT_SAMPLE_DISABLE;
  huart1.Init.ClockPrescaler = UART_PRESCALER_DIV1;
  huart1.AdvancedInit.AdvFeatureInit = UART_ADVFEATURE_NO_INIT;
  if (HAL_UART_Init(&huart1) != HAL_OK)
  {
    Error_Handler();
  }
}

/**
  * @brief USART6 初始化：PC7(RX)，SBUS 100000 8E2，开启 RX 反相
  */
void MX_USART6_UART_Init(void)
{
  huart6.Instance = USART6;
  huart6.Init.BaudRate = 100000;
  huart6.Init.WordLength = UART_WORDLENGTH_9B;
  huart6.Init.StopBits = UART_STOPBITS_2;
  huart6.Init.Parity = UART_PARITY_EVEN;
  huart6.Init.Mode = UART_MODE_RX;
  huart6.Init.HwFlowCtl = UART_HWCONTROL_NONE;
  huart6.Init.OverSampling = UART_OVERSAMPLING_16;
  huart6.Init.OneBitSampling = UART_ONE_BIT_SAMPLE_DISABLE;
  huart6.Init.ClockPrescaler = UART_PRESCALER_DIV1;
  huart6.AdvancedInit.AdvFeatureInit = UART_ADVFEATURE_RXINVERT_INIT;
  huart6.AdvancedInit.RxPinLevelInvert = UART_ADVFEATURE_RXINV_ENABLE;
  if (HAL_UART_Init(&huart6) != HAL_OK)
  {
    Error_Handler();
  }
}

/**
  * @brief SPI1 初始化：陀螺仪1 ICM42688，PA5-SCK PA6-MISO PD7-MOSI
  */
void MX_SPI1_Init(void)
{
  hspi1.Instance = SPI1;
  hspi1.Init.Mode = SPI_MODE_MASTER;
  hspi1.Init.Direction = SPI_DIRECTION_2LINES;
  hspi1.Init.DataSize = SPI_DATASIZE_8BIT;
  hspi1.Init.CLKPolarity = SPI_POLARITY_LOW;
  hspi1.Init.CLKPhase = SPI_PHASE_1EDGE;
  hspi1.Init.NSS = SPI_NSS_SOFT;
  hspi1.Init.BaudRatePrescaler = SPI_BAUDRATEPRESCALER_32;
  hspi1.Init.FirstBit = SPI_FIRSTBIT_MSB;
  hspi1.Init.TIMode = SPI_TIMODE_DISABLE;
  hspi1.Init.CRCCalculation = SPI_CRCCALCULATION_DISABLE;
  hspi1.Init.CRCPolynomial = 0x0;
  if (HAL_SPI_Init(&hspi1) != HAL_OK)
  {
    Error_Handler();
  }
}

/**
  * @brief SPI4 初始化：陀螺仪2 ICM42688，PE12-SCK PE13-MISO PE14-MOSI
  */
void MX_SPI4_Init(void)
{
  hspi4.Instance = SPI4;
  hspi4.Init.Mode = SPI_MODE_MASTER;
  hspi4.Init.Direction = SPI_DIRECTION_2LINES;
  hspi4.Init.DataSize = SPI_DATASIZE_8BIT;
  hspi4.Init.CLKPolarity = SPI_POLARITY_LOW;
  hspi4.Init.CLKPhase = SPI_PHASE_1EDGE;
  hspi4.Init.NSS = SPI_NSS_SOFT;
  hspi4.Init.BaudRatePrescaler = SPI_BAUDRATEPRESCALER_32;
  hspi4.Init.FirstBit = SPI_FIRSTBIT_MSB;
  hspi4.Init.TIMode = SPI_TIMODE_DISABLE;
  hspi4.Init.CRCCalculation = SPI_CRCCALCULATION_DISABLE;
  hspi4.Init.CRCPolynomial = 0x0;
  if (HAL_SPI_Init(&hspi4) != HAL_OK)
  {
    Error_Handler();
  }
}

/* USER CODE END 4 */

 /* MPU Configuration */

void MPU_Config(void)
{
  MPU_Region_InitTypeDef MPU_InitStruct = {0};

  /* Disables the MPU */
  HAL_MPU_Disable();

  /** Initializes and configures the Region and the memory to be protected
  */
  MPU_InitStruct.Enable = MPU_REGION_ENABLE;
  MPU_InitStruct.Number = MPU_REGION_NUMBER0;
  MPU_InitStruct.BaseAddress = 0x0;
  MPU_InitStruct.Size = MPU_REGION_SIZE_4GB;
  MPU_InitStruct.SubRegionDisable = 0x87;
  MPU_InitStruct.TypeExtField = MPU_TEX_LEVEL0;
  MPU_InitStruct.AccessPermission = MPU_REGION_NO_ACCESS;
  MPU_InitStruct.DisableExec = MPU_INSTRUCTION_ACCESS_DISABLE;
  MPU_InitStruct.IsShareable = MPU_ACCESS_SHAREABLE;
  MPU_InitStruct.IsCacheable = MPU_ACCESS_NOT_CACHEABLE;
  MPU_InitStruct.IsBufferable = MPU_ACCESS_NOT_BUFFERABLE;

  HAL_MPU_ConfigRegion(&MPU_InitStruct);

  /* Region 1: UART DMA TX 缓冲区 (0x30000000, 1KB) 置为非 cache，与 DEBUG_MSG_MAX_LEN 对齐 */
  MPU_InitStruct.Number = MPU_REGION_NUMBER1;
  MPU_InitStruct.BaseAddress = 0x30000000;
  MPU_InitStruct.Size = MPU_REGION_SIZE_1KB;
  MPU_InitStruct.SubRegionDisable = 0x00;
  MPU_InitStruct.TypeExtField = MPU_TEX_LEVEL1;
  MPU_InitStruct.AccessPermission = MPU_REGION_FULL_ACCESS;
  MPU_InitStruct.DisableExec = MPU_INSTRUCTION_ACCESS_DISABLE;
  MPU_InitStruct.IsShareable = MPU_ACCESS_NOT_SHAREABLE;
  MPU_InitStruct.IsCacheable = MPU_ACCESS_NOT_CACHEABLE;
  MPU_InitStruct.IsBufferable = MPU_ACCESS_NOT_BUFFERABLE;
  HAL_MPU_ConfigRegion(&MPU_InitStruct);

  /* Enables the MPU */
  HAL_MPU_Enable(MPU_PRIVILEGED_DEFAULT);

}

/**
  * @brief  This function is executed in case of error occurrence.
  * @retval None
  */
void Error_Handler(void)
{
  /* USER CODE BEGIN Error_Handler_Debug */
  /* User can add his own implementation to report the HAL error return state */
  Debug_PanicPrintf("[PANIC] Error_Handler\r\n");
  __disable_irq();
  while (1)
  {
  }
  /* USER CODE END Error_Handler_Debug */
}
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

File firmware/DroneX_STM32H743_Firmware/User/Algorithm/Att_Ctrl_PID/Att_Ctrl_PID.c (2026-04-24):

/**
 * @file Att_Ctrl_PID.c
 * @brief 倒立摆飞行器两轴姿态位置式 PID：roll/pitch 独立控制 X/Y 舵机。
 */

#include "Algorithm/Att_Ctrl_PID/Att_Ctrl_PID.h"
#include "Algorithm/Common/Filter/Filter.h"
#include <math.h>
#include <string.h>

#ifndef ATT_CTRL_PID_PI_F
#define ATT_CTRL_PID_PI_F 3.14159265358979323846f
#endif

typedef struct {
    uint8_t valid;
    Att_Ctrl_PID_Config_t cfg;
    PID_t pid_roll_angle;
    PID_t pid_pitch_angle;
    PID_t pid_roll_rate;
    PID_t pid_pitch_rate;
    Filter_t gyro_lpf[2];
} Att_Ctrl_PID_State_t;

static Att_Ctrl_PID_State_t s_ac;

static float ac_clampf(float x, float lo, float hi)
{
    if (x < lo) {
        return lo;
    }
    if (x > hi) {
        return hi;
    }
    return x;
}

/** 最短角差 wrap 到 (-π, π] */
static float angle_err_rad(float sp_rad, float meas_rad)
{
    float e = sp_rad - meas_rad;
    while (e > ATT_CTRL_PID_PI_F) {
        e -= 2.0f * ATT_CTRL_PID_PI_F;
    }
    while (e <= -ATT_CTRL_PID_PI_F) {
        e += 2.0f * ATT_CTRL_PID_PI_F;
    }
    return e;
}

static int pid_apply_limits(PID_t *pid, float out_min, float out_max,
    uint8_t i_en, float i_min, float i_max)
{
    int rc;

    rc = PID_SetOutputLimits(pid, &out_min, &out_max);
    if (rc != PID_OK) {
        return ATT_CTRL_PID_ERR_LIMIT;
    }
    if (i_en) {
        rc = PID_SetIntegralLimits(pid, &i_min, &i_max);
    } else {
        rc = PID_SetIntegralLimits(pid, NULL, NULL);
    }
    if (rc != PID_OK) {
        return ATT_CTRL_PID_ERR_LIMIT;
    }
    return ATT_CTRL_PID_OK;
}

static int validate_cfg(const Att_Ctrl_PID_Config_t *c)
{
    if (c->roll_angle_out_min > c->roll_angle_out_max || c->pitch_angle_out_min > c->pitch_angle_out_max
        || c->roll_rate_out_min > c->roll_rate_out_max || c->pitch_rate_out_min > c->pitch_rate_out_max
        || c->servo_min_norm > c->servo_max_norm) {
        return ATT_CTRL_PID_ERR_LIMIT;
    }
    if (c->enable_roll_angle_i_limit && c->roll_angle_i_min > c->roll_angle_i_max) {
        return ATT_CTRL_PID_ERR_LIMIT;
    }
    if (c->enable_pitch_angle_i_limit && c->pitch_angle_i_min > c->pitch_angle_i_max) {
        return ATT_CTRL_PID_ERR_LIMIT;
    }
    if (c->enable_roll_rate_i_limit && c->roll_rate_i_min > c->roll_rate_i_max) {
        return ATT_CTRL_PID_ERR_LIMIT;
    }
    if (c->enable_pitch_rate_i_limit && c->pitch_rate_i_min > c->pitch_rate_i_max) {
        return ATT_CTRL_PID_ERR_LIMIT;
    }
    if (c->gyro_lpf_tau_s < 0.0f) {
        return ATT_CTRL_PID_ERR_LIMIT;
    }
    return ATT_CTRL_PID_OK;
}

int Att_Ctrl_PID_Init(const Att_Ctrl_PID_Config_t *cfg)
{
    int rc;

    if (cfg == NULL) {
        return ATT_CTRL_PID_ERR_NULL;
    }
    rc = validate_cfg(cfg);
    if (rc != ATT_CTRL_PID_OK) {
        return rc;
    }

    memset(&s_ac, 0, sizeof(s_ac));
    memcpy(&s_ac.cfg, cfg, sizeof(*cfg));

    rc = PID_Init(&s_ac.pid_roll_angle, &cfg->gains_roll_angle);
    if (rc != PID_OK) {
        return ATT_CTRL_PID_ERR_NULL;
    }
    rc = PID_Init(&s_ac.pid_pitch_angle, &cfg->gains_pitch_angle);
    if (rc != PID_OK) {
        return ATT_CTRL_PID_ERR_NULL;
    }
    rc = PID_Init(&s_ac.pid_roll_rate, &cfg->gains_roll_rate);
    if (rc != PID_OK) {
        return ATT_CTRL_PID_ERR_NULL;
    }
    rc = PID_Init(&s_ac.pid_pitch_rate, &cfg->gains_pitch_rate);
    if (rc != PID_OK) {
        return ATT_CTRL_PID_ERR_NULL;
    }
    rc = pid_apply_limits(&s_ac.pid_roll_angle, cfg->roll_angle_out_min, cfg->roll_angle_out_max,
        cfg->enable_roll_angle_i_limit, cfg->roll_angle_i_min, cfg->roll_angle_i_max);
    if (rc != ATT_CTRL_PID_OK) {
        return rc;
    }
    rc = pid_apply_limits(&s_ac.pid_pitch_angle, cfg->pitch_angle_out_min, cfg->pitch_angle_out_max,
        cfg->enable_pitch_angle_i_limit, cfg->pitch_angle_i_min, cfg->pitch_angle_i_max);
    if (rc != ATT_CTRL_PID_OK) {
        return rc;
    }
    rc = pid_apply_limits(&s_ac.pid_roll_rate, cfg->roll_rate_out_min, cfg->roll_rate_out_max,
        cfg->enable_roll_rate_i_limit, cfg->roll_rate_i_min, cfg->roll_rate_i_max);
    if (rc != ATT_CTRL_PID_OK) {
        return rc;
    }
    rc = pid_apply_limits(&s_ac.pid_pitch_rate, cfg->pitch_rate_out_min, cfg->pitch_rate_out_max,
        cfg->enable_pitch_rate_i_limit, cfg->pitch_rate_i_min, cfg->pitch_rate_i_max);
    if (rc != ATT_CTRL_PID_OK) {
        return rc;
    }
    rc = Filter_InitIIR1(&s_ac.gyro_lpf[0], FILTER_SHAPE_LOW_PASS, cfg->gyro_lpf_tau_s);
    if (rc != FILTER_OK) {
        return ATT_CTRL_PID_ERR_LIMIT;
    }
    rc = Filter_InitIIR1(&s_ac.gyro_lpf[1], FILTER_SHAPE_LOW_PASS, cfg->gyro_lpf_tau_s);
    if (rc != FILTER_OK) {
        return ATT_CTRL_PID_ERR_LIMIT;
    }
    s_ac.valid = 1u;
    return ATT_CTRL_PID_OK;
}

void Att_Ctrl_PID_Reset(void)
{
    if (!s_ac.valid) {
        return;
    }
    PID_Reset(&s_ac.pid_roll_angle);
    PID_Reset(&s_ac.pid_pitch_angle);
    PID_Reset(&s_ac.pid_roll_rate);
    PID_Reset(&s_ac.pid_pitch_rate);
    Filter_Reset(&s_ac.gyro_lpf[0]);
    Filter_Reset(&s_ac.gyro_lpf[1]);
}
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

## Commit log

2026-02-01 Add initial project structure and documentation for DroneX UAV
    - Created .gitignore to exclude unnecessary files and directories.
    - Added PLAN.md outlining project concepts, dynamics models, and subsystem planning.
    - Introduced REFERENCES.md for academic references related to thrust vector control and dynamics.
    - Compiled literature summaries in the literature directory, covering key topics such as thrust vector control, inverted pendulum dynamics, coaxial rotor modeling, flight control, and simulation.
    - Established mechanical design documentation, including design goals and constraints for the UAV structure.
    - Set up simulation subsystem with MATLAB/Simulink for dynamics modeling and contr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
2026-02-01 Enhance project documentation and refine design specifications for DroneX UAV
    - Updated PLAN.md to include implemented MATLAB scripts for rigid body dynamics, thrust models, and control algorithms.
    - Clarified design decisions in mechanical documentation, confirming weight limits, frame structure, and propulsion unit specifications.
    - Improved simulation documentation, detailing the structure of MATLAB scripts and simulation plans, including hover verification scenarios.
    - Adjusted parameters in MATLAB scripts for thrust and position control, ensuring alignment with design goals.
    These changes provide clearer guidance for ongoing development and integration of subsystems in the DroneX UAV p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
2026-02-06 Update project documentation and configuration for DroneX UAV
    - Removed Debug directory from .gitignore to allow for debugging files.
    - Updated README.md and PLAN.md to reflect changes in control mechanisms, specifying the use of high-end brushless servos instead of brushless gear motors.
    - Enhanced firmware documentation to clarify the use of high-end brushless servos in the UAV's control system.
    - Added configuration files for Keil uVision project setup, including .uvprojx and .uvoptx files, to streamline development environment setup.
    These updates improve clarity in project documentation and facilitate a smoother development process for the DroneX UAV.
2026-02-12 Implement UART and SPI initialization for DroneX UAV firmware
    - Added functions for initializing USART1 and SPI1/SPI4 peripherals in main.c.
    - Defined corresponding handle structures for UART and SPI in main.h.
    - Implemented HAL_UART_MspInit and HAL_SPI_MspInit functions to configure GPIO and DMA settings for USART1 and SPI1/SPI4.
    - Introduced User_main.c for user-defined initialization and main loop logic, including IMU handling and command processing.
    - Created Attitude application layer for IMU calibration requests and processing.
    - Enhanced Debug_UART for non-blocking UART communication with DMA support.
    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
2026-02-14 Refactor DroneX UAV firmware for enhanced IMU attitude estimation and timing functionality
    - Updated USART1 baud rate to 2,000,000 for improved communication speed.
    - Modified MPU configuration to align with new DMA buffer settings, increasing buffer size to 1KB and changing base address to 0x30000000.
    - Introduced new Timing driver for precise cycle counting and microsecond timing conversion.
    - Implemented dual IMU attitude estimation algorithm, integrating data from two ICM42688 sensors for improved accuracy.
    - Added configuration and implementation files for the attitude estimation algorithm, including necessary header and source files.
    - Enhanced User_main.c to support new timing and att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
2026-03-13 Implement ESC driver and enhance firmware functionality for DroneX UAV
    - Added ESC driver implementation in ESC.c and ESC.h for DShot300 control, enabling bidirectional throttle control for electronic speed controllers.
    - Integrated ESC initialization and control tasks in User_main.c, allowing for dynamic throttle adjustments based on UART input.
    - Updated command handlers to support new power command for ESC configuration via UART.
    - Enhanced debug functionality with blocking print capabilities for improved diagnostics during development.
    - Modified project configuration files to include new ESC driver and related functionalities.
    These changes significantly improve the UAV's motor control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
    [矢量舵盘.stl, 矢量舵盘V1.gcode.3mf, 舵机.gcode.3mf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]
2026-03-19 Implement USART6 support and integrate RC and gimbal control functionality for DroneX UAV
    - Added USART6 initialization and configuration in main.c and HAL_UART_MspInit for enhanced communication.
    - Implemented RC signal processing in RC.c, including frame decoding and normalization for 16 channels.
    - Integrated vector gimbal control with PWM output in Vector_Gimbal.c, allowing for precise control of gimbal axes.
    - Updated User_main.c to initialize and process RC signals and gimbal commands, enhancing UAV control capabilities.
    - Modified project configuration files to include new RC and gimbal driver functionalities.
    These changes significantly improve the UAV's control and responsiveness,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
    [舵机固定件.gcode.3mf, 舵机固定件.stl, 顶盖.gcode.3mf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]
2026-03-29 Enhance DroneX UAV firmware with debug and telemetry improvements
    - Integrated debug functionality with new Debug_PanicPrintf for critical error logging in Error_Handler and fault handlers.
    - Added reset flag logging in main.c to capture system reset reasons during boot.
    - Updated ESC driver to support telemetry data handling, including new structures for telemetry and service state.
    - Refactored ESC command handling to allow telemetry requests and improved service layer for ESC operations.
    - Modified GPIO initialization in ESC configuration for better signal handling.
    These changes enhance the UAV's debugging capabilities and provide valuable telemetry data for improved operational insight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
    [矢量舵盘.gcode.3mf, 矢量舵盘.stl, 矢量舵盘V1.gcode.3mf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]
2026-03-29 Add new PID control algorithm and configuration handling for DroneX UAV
    - Introduced Att_Ctrl_PID.c and Att_Ctrl_PID.h for VTOL attitude control using PID algorithms, enhancing stability and responsiveness.
    - Implemented Cmd_cfg_table.c and Cmd_cfg_table.h for dynamic configuration management, allowing runtime adjustments of parameters via command input.
    - Added Flash_Param.c and Flash_Param.h for internal Flash parameter storage, enabling persistent configuration across power cycles.
    - Updated Cmd_handlers.c to support new configuration commands, facilitating user-defined parameter adjustments.
    - Enhanced project structure with new algorithm and driver files, improving modularity and mainta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
    [Att_Ctrl_PID.c, Att_Ctrl_PID.h, Flash_Param.c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]
2026-03-30 Enhance ESC driver and user main loop for bidirectional DShot support
    - Added bidirectional DShot handling in ESC driver, including telemetry request management and improved GPIO configurations for signal integrity.
    - Updated User_main.c to incorporate bidirectional telemetry logging and state tracking for ESC channels, enhancing feedback and diagnostics.
    - Refactored throttle mapping to support reduced output range for better control precision.
    - Introduced new functions for handling telemetry data and improved error handling in ESC communication.
    These changes significantly improve the UAV's motor control capabilities and telemetry feedback, enabling more responsive and reliable operation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
    [ESC.c, ESC.h, User_main.c]
2026-04-16 feat: Initialize DroneX simulation framework with actuator, allocator, controller, dynamics, estimator, and sensor modules
    - Added actuator module for generating actuator outputs based on control commands.
    - Implemented allocator module to map thrust and torque targets to specific actuator control commands.
    - Created controller module to compare estimated and target poses, generating thrust and torque targets.
    - Developed dynamics module to update the physical state based on actuator outputs.
    - Introduced estimator module to infer body pose from sensor observations.
    - Established sensor module to convert real states into sensor readings with added noise.
    - Configured simulation settings and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
    [actuator.py, allocator.py]
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2026-04-24 feat: Implement filter module and enhance attitude control PID with rate control - Added Filter module with FIR and IIR filter implementations. - Updated Att_Ctrl_PID to include roll and pitch rate c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
    [Att_Ctrl_PID.c, Att_Ctrl_PID.h, User_main.c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]

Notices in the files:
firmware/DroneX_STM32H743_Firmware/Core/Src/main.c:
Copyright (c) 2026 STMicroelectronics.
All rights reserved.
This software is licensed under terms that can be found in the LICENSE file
